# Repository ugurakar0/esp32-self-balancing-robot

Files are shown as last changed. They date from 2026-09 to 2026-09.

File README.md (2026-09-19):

# 🤖 ESP32 Self-Balancing Robot

<p align="center">
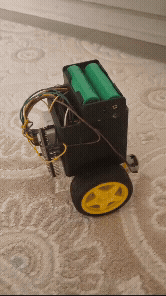
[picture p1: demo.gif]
Kendini Dengeleyen Robot Tanıtımı
  
</p>






A two-wheeled inverted pendulum self-balancing robot built with an ESP32 microcontroller, MPU-6050 6-DOF IMU, L298N dual H-bridge motor driver, and classic Bluetooth Serial teleoperation.

---

## 📑 Table of Contents

- [Key Architectural Features](#-key-architectural-features)
- [Bill of Materials](#-bill-of-materials)
- [3D Printed Parts](#-3d-printed-parts)
- [Control Architecture & Dynamics](#-control-architecture--dynamics)
- [Bluetooth Remote Control](#-bluetooth-remote-control)
- [Live Serial Tuning Interface](#-live-serial-tuning-interface)
- [Hardware Wiring & Pinout](#-hardware-wiring--pinout)
- [Getting Started](#-getting-started)
- [Build Notes & Lessons Learned](#-build-notes--lessons-learned)
- [License](#-license)

---

## 📌 Key Architectural Features

- **Sensor Fusion:** 6-DOF complementary filter combining gyroscope integration with accelerometer gravity reference using dynamic loop intervals ($\Delta t$).
- **Stabilization Loop:** Discrete PID controller operating with anti-windup integral clamping ($\pm 60$) and minimum effective PWM deadband compensation (70–230 range).
- **Time-Based Teleoperation:** Bluetooth driving adjusts the target lean angle over time ($\Delta t$ ramping) instead of injecting raw motor power, preserving dynamic stability.
- **Dynamic Auto-Trim:** Rolling average feedback loop that slowly adjusts the base target angle to compensate for persistent physical steady-state drift.
- **Safety Mechanisms:** Automatic motor cutoff and controller state reset if tilt exceeds $\pm 30^\circ$ or if no valid drive command is received within the watchdog timeout.

---

## 🧰 Bill of Materials

| Qty | Component | Notes |
|:---:|:---|:---|
| 1 | **ESP32 DevKit C** | Main microcontroller |
| 2 | **TT Gear Motor** | Drive motors |
| 2 | **TT Motor Holder** | 3D printed brackets mounting each TT motor to the chassis |
| 1 | **L298N Driver** | Dual H-bridge motor driver |
| 1 | **MPU-6050** | 6-DOF IMU (accelerometer + gyroscope) |
| 2 | **18650 Li-ion Cell** | 2000–2400 mAh each, main power source (2S configuration) |
| 1 | **8×8×8 cm Enclosure** | 3D printed main chassis body with removable lid |

> **Notes on this build:**
> - The MPU-6050 is mounted directly on the enclosure's lid.
> - The chassis is an 8×8×8 cm 3D-printed box with a separate lid; the two TT motors are attached to the sides via the printed TT motor holders.
> - Add your battery holder/BMS, on/off switch, and voltage regulator (if your 2S 18650 pack doesn't match your ESP32/L298N input range) according to your own wiring.

---

## 🖨️ 3D Printed Parts

| Part | File | Status |
|:---|:---:|:---|
| **TT Motor Holder ×2** | `tt_motor_tutucu.stl` | ✅ Included in this repo |
| **8×8×8 cm Enclosure + Lid** | — | ⚠️ Designed for this build but the source/STL was lost — not yet available. If re-created, it will be added here. |

> **Suggested repo structure:** Place printable files under an `stl/` (or `hardware/`) folder so they are easy to locate separately from the firmware.

---

## 🧠 Control Architecture & Dynamics

The system maintains balance by modeling the chassis as an inverted pendulum. Balance (pitch) and steering (yaw) control are handled through separate control paths.

### 1. Angle Estimation (Complementary Filter)
$$\theta = 0.96 \cdot (\theta + \omega_{gyro} \cdot \Delta t) + 0.04 \cdot \theta_{acc}$$
Reduces high-frequency accelerometer noise while compensating for long-term gyroscope drift.

### 2. Discrete PID Formulation
$$u[k] = K_p \cdot e[k] + K_i \sum_{j=0}^{k} e[j] \Delta t_j + K_d \frac{e[k] - e[k-1]}{\Delta t_k}$$
- **Anti-Windup:** Integral accumulation is clamped within $[-60.0, 60.0]$ to limit integral windup during actuator saturation.
- **Deadband Compensation:** Overcomes DC motor static friction with conditional PWM lower bounds.

---

## 🎮 Bluetooth Remote Control

The robot hosts an SPP (Serial Port Profile) server advertised as **`DengeRobot`**. It can be controlled using apps like *Arduino Bluetooth Controller* in pad mode:

| Key | Action | Dynamic Implementation |
|:---:|:---|:---|
| **W** | Forward | Positively ramps target pitch angle (`moveTilt`) |
| **S** | Backward | Negatively ramps target pitch angle (`moveTilt`) |
| **A** | Turn Left | Offsets wheel differential (`turnBias`) negatively |
| **D** | Turn Right | Offsets wheel differential (`turnBias`) positively |
| **L** | Stop / Idle | Resets lean angle target to base balance reference |

> **Watchdog Failsafe:** If no valid command packet is received within `btTimeout` (default: 600 ms), the robot resets tilt offsets to zero.

---

## 🛠️ Live Serial Tuning Interface

PID gains and control parameters can be tuned in real time over the USB Serial Monitor (115200 baud) without recompiling:

| Command | Parameter | Description |
|:---|:---|:---|
| `p<value>` | Proportional Gain ($K_p$) | Balances corrective reaction force (default: `15.0`) |
| `i<value>` | Integral Gain ($K_i$) | Clears steady-state error & resets accumulator (default: `0.71`) |
| `d<value>` | Derivative Gain ($K_d$) | Dampens tilt vibrations & overshoots (default: `0.44`) |
| `t<value>` | Base Target Angle | Calibrates physical center-of-mass balance point |
| `a1` / `a0` | Auto-Trim Toggle | Enables/disables rolling average drift compensation |
| `m<value>` | Max Lean Angle | Sets maximum forward/backward lean tilt (deg) |
| `n<value>` | Max Turn Strength | Sets maximum turning speed bias |
| `r<value>` | Tilt Ramp Time | Acceleration ramp duration (seconds) |
| `u<value>` | Turn Ramp Time | Yaw transition ramp duration (seconds) |
| `x<value>` | Watchdog Timeout | Communication timeout trigger limit (ms) |

---

## ⚡ Hardware Wiring & Pinout

| Module | Pin Name | ESP32 GPIO | Description |
|:---|:---|:---|:---|
| **MPU-6050** | SDA | GPIO 21 | I2C Data |
| **MPU-6050** | SCL | GPIO 22 | I2C Clock |
| **L298N Driver** | ENA | GPIO 14 | Left Motor PWM Speed |
| **L298N Driver** | IN1 / IN2 | GPIO 27 / GPIO 26 | Left Motor Direction Pins |
| **L298N Driver** | ENB | GPIO 12 | Right Motor PWM Speed |
| **L298N Driver** | IN3 / IN4 | GPIO 25 / GPIO 33 | Right Motor Direction Pins |
| **Power / Ground** | GND | GND | Common ground reference across all modules |

### 📐 Circuit Schematic

<p align="center">
  Hardware Circuit Schematic
</p>

---

## 🚀 Getting Started

1. Install the ESP32 board package in Arduino IDE (**Boards Manager** → search `esp32` → install). Select **ESP32 Dev Module** as the target board.
2. Install required libraries via the Arduino Library Manager:
   - `Adafruit MPU6050`
   - `Adafruit Unified Sensor`
   - `BluetoothSerial` (bundled with ESP32 core)
3. Wire the hardware according to the pinout table above.
4. Flash the firmware and open the Serial Monitor at **115200 baud**.
5. Pair your phone's Bluetooth with the device named **`DengeRobot`** and connect using a pad-style BT controller app.
6. Stand the robot upright, then tune $K_p$, $K_i$, $K_d$, and the base target angle live over Serial.

---

## 🧩 Build Notes & Lessons Learned

Real issues encountered during this build, documented to accelerate future revisions:

- **Reversed Motor Wiring (Compensated in Software):** The two TT motors were initially wired with opposite polarity, preventing the platform from achieving equilibrium (one wheel continuously opposed balance). Rather than desoldering hardware leads, polarity inversion was mapped directly inside `driveMotors()` in firmware.
- **Inverted MPU-6050 Mounting Orientation:** Mounting the IMU onto the top lid inverted the sign of raw tilt angles. Ensure coordinate system alignment is verified early—sign mismatches cause PID feedback and auto-trim loops to amplify tilt rather than correct it.
- **Empirical PID Tuning Strategy:** Tuning required establishing wide discrete test bounds rather than micro-adjustments:
  - **$K_p$:** Test in coarse intervals (`3, 6, 9, 12, 15, 18`) to quickly identify the stability threshold.
  - **$K_d$:** Usable damping range landed around `0.01 – 0.9`.
  - **$K_i$:** Keep low (`0 – 0.5`) to eliminate steady-state tilt without introducing slow hunting oscillations.
  - *Tuning flow:* Increase $K_p$ until the chassis balances with moderate wobble, introduce $K_d$ to suppress oscillations, and apply minimal $K_i$ only to clear persistent steady-state offset.
- **Physical Zero vs. Sensor Zero:** The base balance angle rarely sits at nominal $0.0^\circ$ due to center-of-mass variations (battery and lid placement). Identify the mechanical equilibrium angle empirically per assembly using the `t<value>` command.

---

## 📄 License
This project is open-source and distributed under the [MIT License](LICENSE).

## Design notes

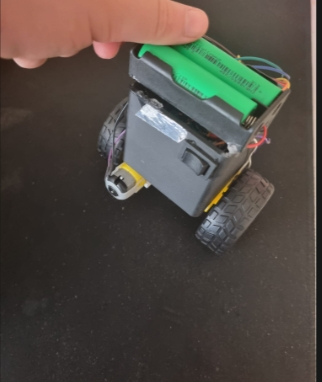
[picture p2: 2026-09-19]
robot_overview.png

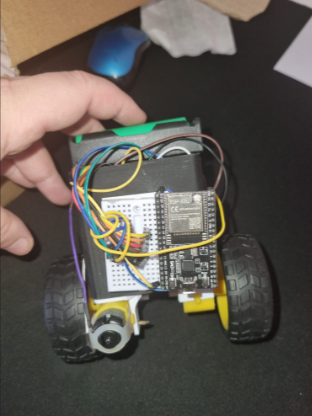
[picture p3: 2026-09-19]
robot_front_view.png

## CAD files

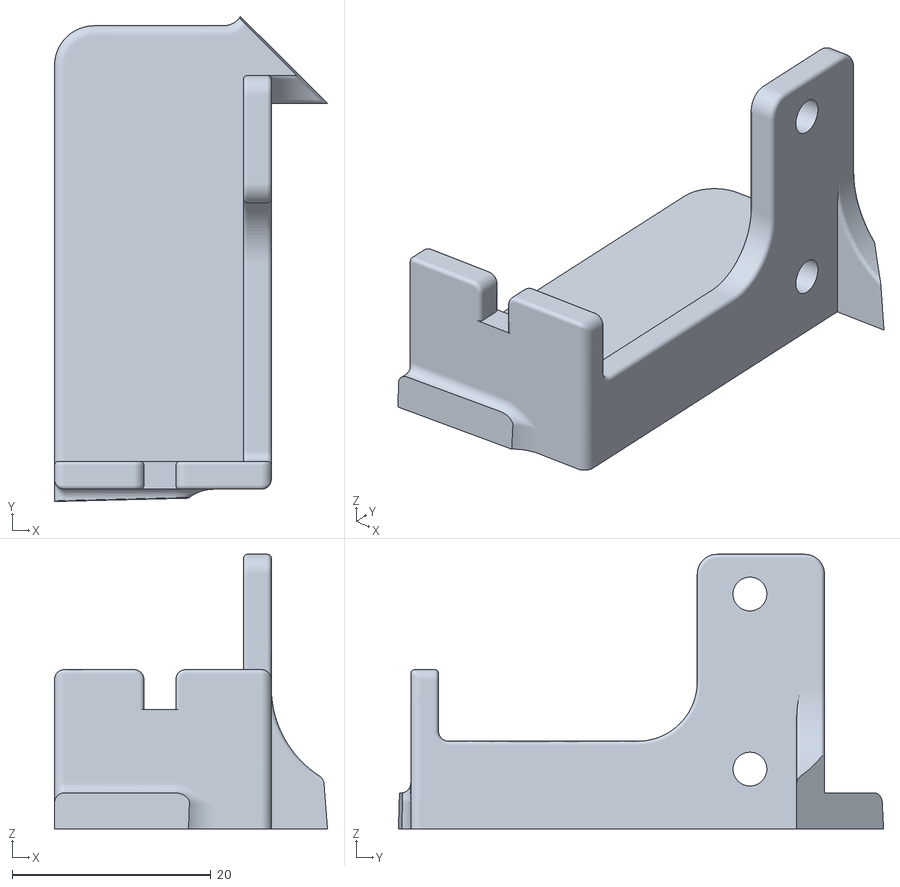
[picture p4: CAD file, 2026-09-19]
tt motor tutucu.stl
27.4 x 48.8 x 27.6

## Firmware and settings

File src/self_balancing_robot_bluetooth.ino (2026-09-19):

/* =============================================================================
   SELF-BALANCING ROBOT — MPU6050 + L298N + PID + Bluetooth (ESP32)
   =============================================================================
   This sketch balances a two-wheeled robot using a PID controller fed by an
   MPU6050 IMU, and lets you drive it (forward/back/turn) over classic
   Bluetooth Serial from a phone app such as "Arduino Bluetooth Controller"
   in "pad" mode.

   -----------------------------------------------------------------------
   QUICK TUNING CHEAT-SHEET (type these into the Serial Monitor, 115200 baud)
   -----------------------------------------------------------------------
     p<value>   Set Kp                  e.g. p15.0
     i<value>   Set Ki (resets integral) e.g. i0.7
     d<value>   Set Kd                  e.g. d0.44
     t<value>   Set target balance angle (baseTargetAngle) e.g. t3.0
     a1 / a0    Turn auto-trim ON / OFF
     m<value>   Set max forward/backward lean angle (deg)   e.g. m0.6
     n<value>   Set max turn strength                       e.g. n10
     r<value>   Set forward/backward ramp time (seconds)    e.g. r0.8
     u<value>   Set turn ramp time (seconds)                e.g. u1.2
     x<value>   Set Bluetooth failsafe timeout (ms)         e.g. x600

   Bluetooth phone app (pair with "DengeRobot"):
     W = forward   S = backward   A = left   D = right   L = stop

   -----------------------------------------------------------------------
   WHY THE BLUETOOTH DRIVING FELT BAD BEFORE (read this if things are still
   not smooth after flashing this version) — see chat explanation as well:
   -----------------------------------------------------------------------
   1) The forward/backward "lean" used to ramp up by a FIXED AMOUNT PER LOOP
      ITERATION instead of a fixed amount PER SECOND. Since loop speed is
      not perfectly constant (sensor reads, BT reads, etc. all take a
      variable amount of time), a short press vs a long press produced
      very inconsistent results. This version ramps based on elapsed time
      (dt), so the behaviour is now consistent no matter how fast the loop
      runs. Tune the "feel" with r<value> / u<value> (ramp time in seconds)
      instead of guessing at a per-loop step size.

   2) BT_TIMEOUT (the "no command received -> stop" failsafe) was only
      300 ms. Classic Bluetooth Serial can have latency spikes, and many
      phone "pad" apps only resend the held key every 100-300 ms. If a
      packet is a little late, the robot thinks the button was released
      and snaps back to a zero lean target, which mid-drive can be enough
      to tip an already marginally-tuned balance loop over. This is
      raised to 600 ms by default and is now live-tunable with x<value>
      so you can find the smallest safe value for your specific phone app.

   3) The maximum forward/backward lean (MOVE_TILT_MAX) is only ~1 degree
      by design — that's intentional and safe. If the robot falls as soon
      as you start driving, the balance PID itself is likely tuned right
      at the edge of stability (fine when sitting still, not fine once you
      ask it to also track a moving target angle). Re-tune Kp/Ki/Kd with
      the robot actually being nudged by hand before trusting BT driving,
      and consider lowering m<value> even further (e.g. 0.3-0.5) while you
      dial in the PID gains.

   4) Fixed a bug where auto-trim adjusted "targetAngle" directly, but
      targetAngle is recalculated from baseTargetAngle + moveTilt on every
      single loop anyway — so the auto-trim correction was being silently
      discarded every iteration. Auto-trim now correctly adjusts
      baseTargetAngle instead.
   ========================================================================= */

#include <Wire.h>
#include <Adafruit_MPU6050.h>
#include <Adafruit_Sensor.h>
#include "BluetoothSerial.h"

Adafruit_MPU6050 mpu;
BluetoothSerial SerialBT;

// ---------------------------------------------------------------------------
// L298N MOTOR DRIVER PINS
// ---------------------------------------------------------------------------
// ENA/ENB are the PWM speed pins, IN1..IN4 set direction for each motor.
// Change these if your wiring is different.
#define ENA 14
#define IN1 27
#define IN2 26
#define ENB 12
#define IN3 25
#define IN4 33

#define PWM_FREQ 1000   // PWM frequency for the motor driver (Hz)
#define PWM_RES  8      // PWM resolution in bits (8-bit -> 0-255 duty range)

// ---------------------------------------------------------------------------
// LIVE-TUNABLE PID VALUES (balance controller)
// ---------------------------------------------------------------------------
// These are the core "how hard does the robot correct itself" gains.
//   Kp -> proportional: bigger = reacts harder to the current tilt error
//   Ki -> integral: bigger = corrects small steady-state lean faster,
//         but too high causes slow oscillation / overshoot
//   Kd -> derivative: bigger = resists fast tilt changes (damping),
//         too high makes the robot twitchy/noisy
// Tune in this order: raise Kp until it balances but wobbles, add Kd to
// damp the wobble, then add a small amount of Ki to kill any steady lean.
double Kp = 15.0;
double Ki = 0.71;
double Kd = 0.44;

// The angle (in degrees, as measured by the IMU) at which the robot is
// considered "upright". This is NOT necessarily 0 -- it depends on where
// the IMU is physically mounted, so you'll need to find this value by
// trial and error (use the 't' serial command).
double baseTargetAngle = 3.0;

double targetAngle = baseTargetAngle; // actual angle the PID is chasing right now
double currentAngle = 0.0;            // filtered current tilt angle (complementary filter)
double error = 0.0, prevError = 0.0;
double integral = 0.0, derivative = 0.0;
double pidOutput = 0.0;

// ---------------------------------------------------------------------------
// AUTO-TRIM (drift correction)
// ---------------------------------------------------------------------------
// If the robot consistently drifts/leans one way even while "balanced",
// it usually means baseTargetAngle isn't perfectly matched to the real
// mechanical balance point. Auto-trim watches the long-term average PID
// output and, if enabled, very slowly nudges baseTargetAngle toward the
// value that would make that average zero.
bool autoTrim = false;     // enable with 'a1', disable with 'a0'
double trimRate = 0.0005;  // how fast auto-trim corrects. Keep VERY small.
                            // If it makes drift WORSE, flip the sign in the
                            // "if (autoTrim)" block below.
double outputAvg = 0.0;    // slow (long-term) rolling average of pidOutput

unsigned long lastTime = 0;
double dt = 0.01; // loop time delta in seconds, recalculated every loop

// =============================================================================
// BLUETOOTH DRIVE CONTROL
// =============================================================================
// Design idea: instead of feeding raw speed to the motors (which would
// fight the balance PID and make the robot fall), driving forward/backward
// is done by very gently LEANING the balance target angle in that
// direction. The balance PID then naturally drives the wheels to "chase"
// that lean, producing smooth acceleration. Left/right turning is done by
// giving the two wheels a small opposite speed offset (turnBias) around
// their shared PID output -- this only affects yaw (spin), not pitch
// (front/back balance), so it doesn't fight the balance loop at all.

double moveTilt = 0.0;   // current forward/backward lean added to baseTargetAngle
double turnBias = 0.0;   // current left/right wheel speed difference

// --- Tunable via serial commands (m / n / r / u / x) ---
double moveTiltMax   = 1.0;   // 'm' — maximum forward/back lean angle (deg).
                               //       Bigger = more aggressive top speed,
                               //       but also easier to destabilize the
                               //       balance loop. Start small (0.3-0.6).
double turnMax        = 12.0; // 'n' — maximum turn strength.
                               //       Bigger = faster spin on A/D.
double moveTiltRampTime = 0.6; // 'r' — seconds to go from 0 to moveTiltMax.
                                //       Bigger = gentler/slower acceleration.
double turnRampTime     = 1.0; // 'u' — seconds to go from 0 to turnMax.
                                //       Bigger = gentler turn start.

char btCommand = 'L';
unsigned long lastBtCommandTime = 0;
// Failsafe: if no valid BT command is received for this long, assume the
// connection dropped or the button was released, and stop. Raised from the
// original 300 ms because classic Bluetooth Serial can have latency spikes
// that were causing false "release" events mid-drive. Tune with 'x'.
unsigned long btTimeout = 600;
// ===========================================================================

void driveMotors(double output);
void stopMotors();
void readSerialCommands();
void readBluetoothCommands();

void setup() {
  Serial.begin(115200);
  delay(500);

  pinMode(IN1, OUTPUT); pinMode(IN2, OUTPUT);
  pinMode(IN3, OUTPUT); pinMode(IN4, OUTPUT);

  #if defined(ESP_ARDUINO_VERSION_MAJOR) && (ESP_ARDUINO_VERSION_MAJOR >= 3)
    ledcAttach(ENA, PWM_FREQ, PWM_RES);
    ledcAttach(ENB, PWM_FREQ, PWM_RES);
  #else
    ledcSetup(0, PWM_FREQ, PWM_RES); ledcAttachPin(ENA, 0);
    ledcSetup(1, PWM_FREQ, PWM_RES); ledcAttachPin(ENB, 1);
  #endif

  Wire.begin(21, 22); // SDA=21, SCL=22 — change if your IMU is wired differently
  if (!mpu.begin(0x68, &Wire)) {
    Serial.println("ERROR: MPU6050 not found!");
    while (1) delay(10);
  }

  mpu.setAccelerometerRange(MPU6050_RANGE_4_G);
  mpu.setGyroRange(MPU6050_RANGE_500_DEG);
  mpu.setFilterBandwidth(MPU6050_BAND_21_HZ);

  SerialBT.begin("DengeRobot"); // Bluetooth device name — pair your phone to this
  Serial.println("Bluetooth is active. Pair your phone with 'DengeRobot'.");

  lastTime = micros();
  Serial.println("\n=== Self-Balancing Robot Started ===");
  Serial.println("Serial tuning commands: p / i / d / t / a / m / n / r / u / x  (see header comment)");
  Serial.println("Bluetooth commands: W forward, S backward, A left, D right, L stop");
}

void loop() {
  // --- Compute the loop time delta FIRST, so both the Bluetooth ramp logic
  //     and the PID controller use a fresh, consistent dt this iteration. ---
  unsigned long now = micros();
  dt = (now - lastTime) / 1000000.0;
  if (dt <= 0.0) dt = 0.005;
  lastTime = now;

  readSerialCommands();
  readBluetoothCommands(); // uses dt above to ramp moveTilt/turnBias smoothly

  sensors_event_t a, g, temp;
  mpu.getEvent(&a, &g, &temp);

  // Complementary filter: mostly trust the gyro (smooth, drifts slowly),
  // and slowly correct with the accelerometer (noisy, but doesn't drift).
  // 0.96/0.04 is a common starting split; raise the gyro weight (e.g. 0.98)
  // for a smoother but slower-to-correct angle estimate.
  double accAngle = atan2(a.acceleration.x, -a.acceleration.z) * 57.2957795;
  double gyroRate = g.gyro.y * 57.2957795;
  currentAngle = 0.96 * (currentAngle + gyroRate * dt) + 0.04 * accAngle;

  // Safety cutoff: if the robot has tipped over too far to recover
  // (e.g. picked up, or already fallen), stop the motors instead of
  // fighting the ground, and reset the integral/derivative state so it
  // doesn't lurch when picked back up.
  if (abs(currentAngle - targetAngle) > 30.0) {
    stopMotors();
    integral = 0;
    prevError = 0;
  } else {
    error = targetAngle - currentAngle;

    integral += error * dt;
    integral = constrain(integral, -60.0, 60.0); // anti-windup clamp

    derivative = (error - prevError) / dt;
    prevError = error;

    pidOutput = (Kp * error) + (Ki * integral) + (Kd * derivative);
    driveMotors(pidOutput);

    // --- AUTO-TRIM ---
    // Track a very slow rolling average of pidOutput. If the robot is
    // balanced but the average output is consistently non-zero, that
    // means baseTargetAngle is slightly off from the true mechanical
    // balance point. When enabled, slowly nudge baseTargetAngle to
    // cancel that average out.
    outputAvg = outputAvg * 0.999 + pidOutput * 0.001;

    if (autoTrim) {
      baseTargetAngle -= outputAvg * trimRate;
      // NOTE: if this makes drift WORSE instead of better, your motor/
      // mounting orientation needs the opposite sign — change the line
      // above to "+=".
    }
  }

  static unsigned long lastLog = 0;
  if (millis() - lastLog > 100) {
    lastLog = millis();
    Serial.print("Angle: ");   Serial.print(currentAngle);
    Serial.print(" | Target: "); Serial.print(targetAngle);
    Serial.print(" | OutAvg: "); Serial.print(outputAvg);
    Serial.print(" | Kp: ");   Serial.print(Kp);
    Serial.print(" | Ki: ");   Serial.print(Ki);
    Serial.print(" | Kd: ");   Serial.print(Kd);
    Serial.print(" | PID: "); Serial.println(pidOutput);
  }

  delay(4);
}

// ---------------------------------------------------------------------------
// Drives each wheel independently. Pitch (front/back balance) depends on
// the AVERAGE of the two wheels' commanded speed, while turning depends
// on the DIFFERENCE between them — so the two behaviors are fully
// independent and turning never fights the balance PID.
// ---------------------------------------------------------------------------
void driveMotors(double output) {
  double leftCmd  = output + turnBias;
  double rightCmd = output - turnBias;

  int speedL = 0, speedR = 0;

  // Motors need a minimum PWM value to actually overcome friction and
  // start turning ("deadzone"). 70 is the minimum "starts moving" duty
  // cycle and 230 is the practical top speed (out of 255) — adjust these
  // two numbers to match your specific motors if they stall or are too
  // fast/slow near the limits.
  if (abs(leftCmd) >= 0.05) {
    speedL = map((int)abs(leftCmd), 0, 100, 70, 230);
    speedL = constrain(speedL, 70, 230);
  }
  if (abs(rightCmd) >= 0.05) {
    speedR = map((int)abs(rightCmd), 0, 100, 70, 230);
    speedR = constrain(speedR, 70, 230);
  }

  // Left wheel direction (same polarity as the original IN1/IN2 wiring)
  if (leftCmd < 0) { digitalWrite(IN1, LOW);  digitalWrite(IN2, HIGH); }
  else              { digitalWrite(IN1, HIGH); digitalWrite(IN2, LOW);  }

  // Right wheel direction (same polarity as the original IN3/IN4 wiring)
  if (rightCmd < 0) { digitalWrite(IN3, HIGH); digitalWrite(IN4, LOW);  }
  else               { digitalWrite(IN3, LOW);  digitalWrite(IN4, HIGH); }

  #if defined(ESP_ARDUINO_VERSION_MAJOR) && (ESP_ARDUINO_VERSION_MAJOR >= 3)
    ledcWrite(ENA, speedL);
    ledcWrite(ENB, speedR);
  #else
    ledcWrite(0, speedL);
    ledcWrite(1, speedR);
  #endif
}

void stopMotors() {
  digitalWrite(IN1, LOW); digitalWrite(IN2, LOW);
  digitalWrite(IN3, LOW); digitalWrite(IN4, LOW);
  #if defined(ESP_ARDUINO_VERSION_MAJOR) && (ESP_ARDUINO_VERSION_MAJOR >= 3)
    ledcWrite(ENA, 0); ledcWrite(ENB, 0);
  #else
    ledcWrite(0, 0); ledcWrite(1, 0);
  #endif
}

// ---------------------------------------------------------------------------
// USB Serial tuning commands. Type a letter immediately followed by a
// number and press Enter, e.g.  p15.5
// ---------------------------------------------------------------------------
void readSerialCommands() {
  if (Serial.available()) {
    char type = Serial.read();
    double val = Serial.parseFloat();

    if (type == 'p') {
      Kp = val;
      Serial.print("-> Kp updated: "); Serial.println(Kp);
    } else if (type == 'i') {
      Ki = val;
      integral = 0; // reset so a big Ki change doesn't cause a sudden kick
      Serial.print("-> Ki updated: "); Serial.println(Ki);
    } else if (type == 'd') {
      Kd = val;
      Serial.print("-> Kd updated: "); Serial.println(Kd);
    } else if (type == 't') {
      baseTargetAngle = val;
      Serial.print("-> Base target angle updated: "); Serial.println(baseTargetAngle);
    } else if (type == 'a') {
      autoTrim = (val != 0);
      outputAvg = 0;
      Serial.print("-> Auto-trim: "); Serial.println(autoTrim ? "ON" : "OFF");
    } else if (type == 'm') {
      moveTiltMax = val;
      Serial.print("-> Max forward/back lean updated: "); Serial.println(moveTiltMax);
    } else if (type == 'n') {
      turnMax = val;
      Serial.print("-> Max turn strength updated: "); Serial.println(turnMax);
    } else if (type == 'r') {
      moveTiltRampTime = max(val, 0.05); // avoid 0/negative -> divide-by-zero
      Serial.print("-> Forward/back ramp time (s) updated: "); Serial.println(moveTiltRampTime);
    } else if (type == 'u') {
      turnRampTime = max(val, 0.05);
      Serial.print("-> Turn ramp time (s) updated: "); Serial.println(turnRampTime);
    } else if (type == 'x') {
      btTimeout = (unsigned long) max(val, 50.0); // don't allow an unsafe 0 ms timeout
      Serial.print("-> Bluetooth failsafe timeout (ms) updated: "); Serial.println(btTimeout);
    }
  }
}

// ---------------------------------------------------------------------------
// Reads the latest Bluetooth drive command and smoothly ramps the
// forward/backward lean (moveTilt) and turn offset (turnBias) toward it
// over time, instead of jumping instantly — this is what keeps driving
// from fighting/destabilizing the balance PID.
//
// A phone Bluetooth-control app (e.g. "Arduino Bluetooth Controller" in
// pad mode) typically re-sends the held key's character repeatedly while
// pressed, and sends a different character (here treated as anything
// other than W/S/A/D, commonly mapped to 'L') when released. This
// function keeps the last recognized command and, if nothing valid is
// heard for `btTimeout` ms, treats that as "released" and stops as a
// safety failsafe.
// ---------------------------------------------------------------------------
void readBluetoothCommands() {
  if (SerialBT.available()) {
    char c = toupper(SerialBT.read());
    if (c == 'W' || c == 'S' || c == 'A' || c == 'D' || c == 'L') {
      btCommand = c;
      lastBtCommandTime = millis();
    }
  }

  // Safety failsafe: if the connection drops or the command stream stops
  // arriving, automatically stop driving.
  if (millis() - lastBtCommandTime > btTimeout) {
    btCommand = 'L';
  }

  // --- FORWARD / BACKWARD: ramp moveTilt toward its target over time ---
  double tiltTarget = 0.0;
  if (btCommand == 'W') tiltTarget = moveTiltMax;
  else if (btCommand == 'S') tiltTarget = -moveTiltMax;

  // Time-based ramp: moves at a constant deg/second rate regardless of
  // how fast/slow the loop happens to be running this cycle.
  double tiltStep = (moveTiltMax / moveTiltRampTime) * dt;
  if (moveTilt < tiltTarget)      moveTilt = min(moveTilt + tiltStep, tiltTarget);
  else if (moveTilt > tiltTarget) moveTilt = max(moveTilt - tiltStep, tiltTarget);

  targetAngle = baseTargetAngle + moveTilt;

  // --- LEFT / RIGHT: ramp turnBias toward its target over time ---
  double turnTarget = 0.0;
  if (btCommand == 'D') turnTarget = turnMax;
  else if (btCommand == 'A') turnTarget = -turnMax;

  double turnStep = (turnMax / turnRampTime) * dt;
  if (turnBias < turnTarget)      turnBias = min(turnBias + turnStep, turnTarget);
  else if (turnBias > turnTarget) turnBias = max(turnBias - turnStep, turnTarget);
}

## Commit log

2026-09-19 Add 3D printable TT motor bracket STL
    [tt motor tutucu.stl]
2026-09-19 Add KiCad circuit schematic

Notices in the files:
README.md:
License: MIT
